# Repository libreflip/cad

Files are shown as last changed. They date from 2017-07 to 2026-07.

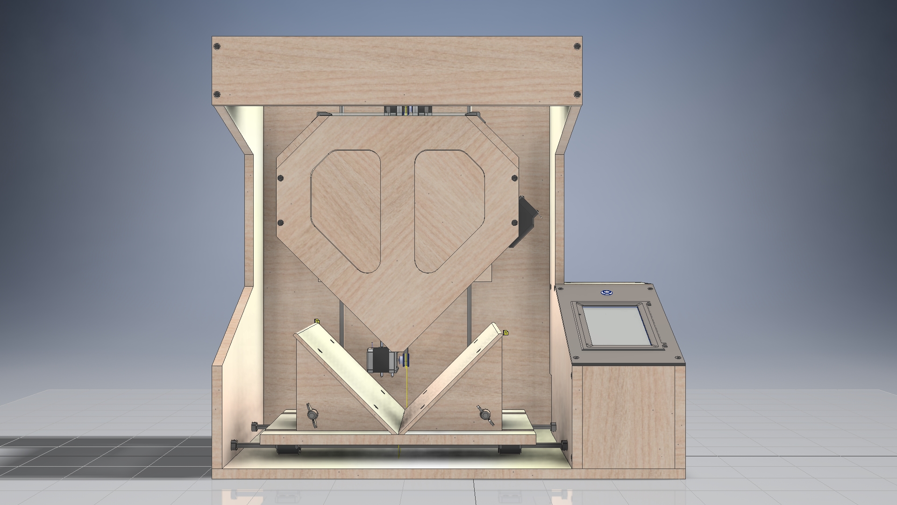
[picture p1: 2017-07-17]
img/complete5.jpg

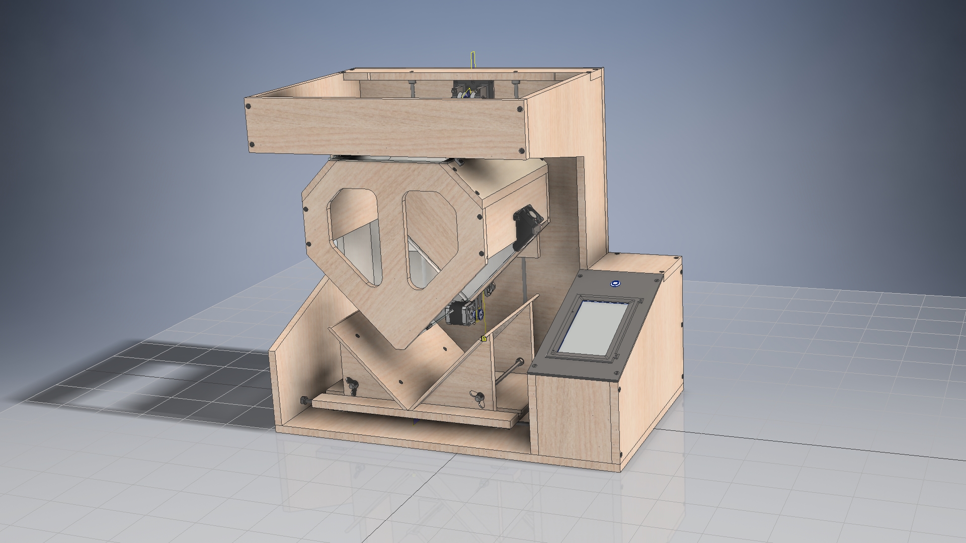
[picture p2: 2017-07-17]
img/complete1.jpg

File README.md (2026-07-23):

# Libreflip — CAD

CAD and mechanical design data for Libreflip, an open-source, automated
book scanner built at c-base Berlin.

## Contents

| Directory/File | Contents |
|---|---|
| `3d-printed/FDM/` | 3D-printable parts for standard FDM printers |
| `3d-printed/SLA/` | 3D-printable parts for resin/SLA printers |
| `drawings/` | Technical drawings (PDF) of major assemblies (backplate, suction box, fan shroud, electronics housing, bookholder, connector plate, light assembly, overview) |
| `img/` | Photos of the assembled machine |
| `plot/` | Parts list plots/exports |
| `bom_neu.ods` | Bill of materials |

## File naming

Printable parts are prefixed with the quantity needed, e.g.
`2pcs-camera-holder-movable.stl` means two of that part are required.

## ⚠️ Outdated files

`drawings/` (last updated 2018-12-31) and `plot/` (last updated 2017-07-17)
have not been updated since. Current changes and ongoing development are
**not** reflected in these files — check the individual 3D-printed part
files and their commit history for the current state instead.

## Related repositories

- [`sans`](https://github.com/libreflip/sans) — command & control software
- [`serif`](https://github.com/libreflip/serif) — web frontend
- [`monospace`](https://github.com/libreflip/monospace) — bookscanner controller firmware
- [`kerning`](https://github.com/libreflip/kerning) — deployment utilities

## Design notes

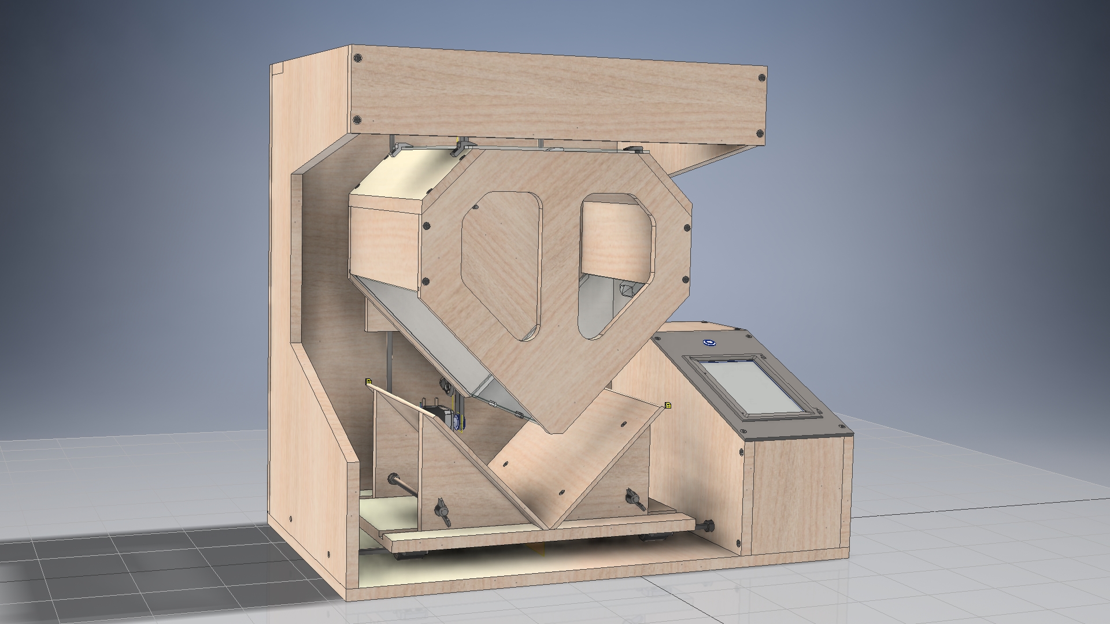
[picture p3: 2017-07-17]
img/complete2.jpg

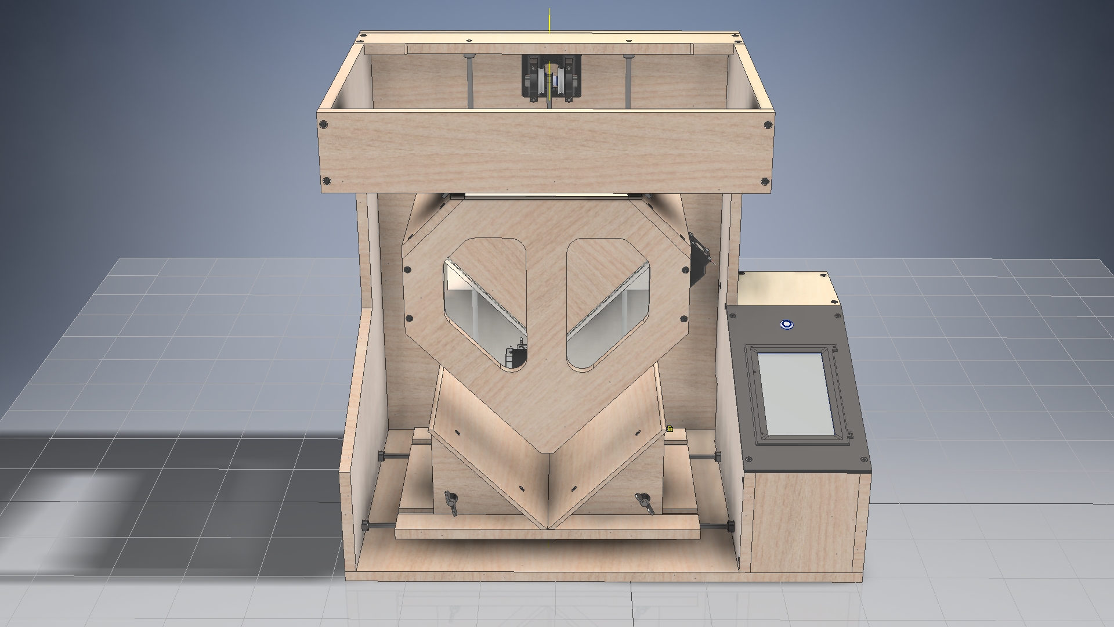
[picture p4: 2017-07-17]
img/complete6.jpg

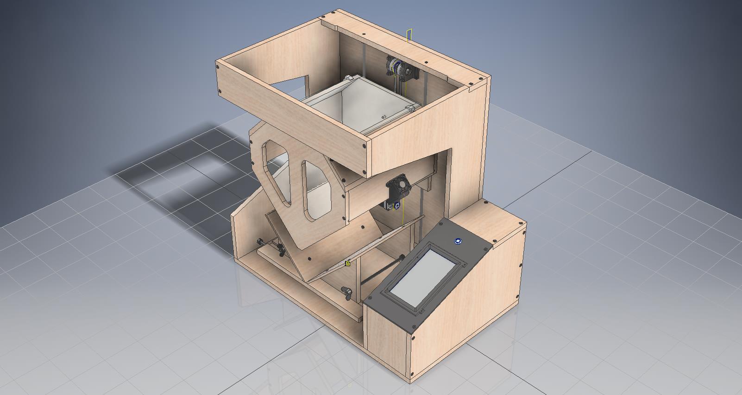
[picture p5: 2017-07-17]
img/complete3.jpg

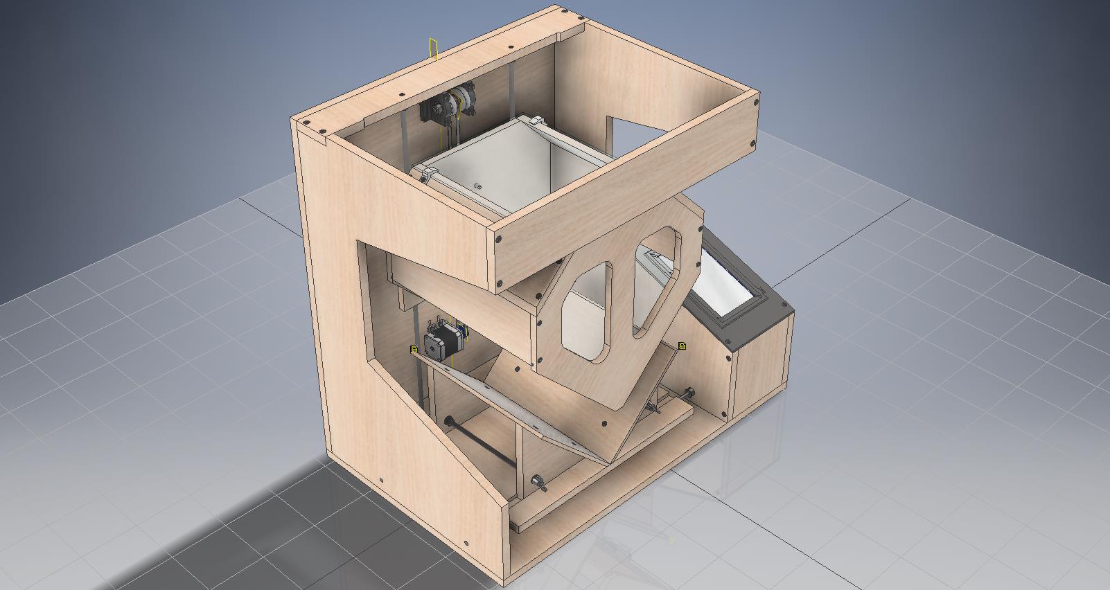
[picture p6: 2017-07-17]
img/complete4.jpg

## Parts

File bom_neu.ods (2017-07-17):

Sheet: complete-BOM
Part Number | BOM Structure | Unit QTY | QTY | Stock Number | Description | mm² | Artikel-Nr | Shop | Shoplink | Gebindegröße | Gebindepreis | Einzelpreis | Gebindemenge | Gesamtpreis | Überschuss | Preis Überschuss
5pol Kabel | Purchased |  | 1 |  | Drucksensorkabel |  |  | 0 | 0 |  | 0 | #DIV/0! | #DIV/0!
same as drucksensor kabel | Purchased |  | 1 |  | Endschalterkabel |  |  | 0 | 0 | 0 | 0 | #DIV/0! | #DIV/0!
0 | Purchased |  | 1 |  | Beleuchtungskabel |  |  | 0 | 0 | 1 | 0 | 0,0000 € | 1 | 0,00 €
0 | Purchased |  | 1 |  | Gummifedern |  |  | 0 | 0 | 1 | 0 | 0,0000 € | 1 | 0,00 €
0 | Purchased |  | 1 |  | Saugschlauch |  |  | 0 | 0 | 1 | 0 | 0,0000 € | 1 | 0,00 €
0 | Purchased |  | 1 |  | Blasschlauch |  |  | 0 | 0 | 1 | 0 | 0,0000 € | 1 | 0,00 €
0 | Purchased |  | 1 |  | Blasdüse |  |  | 0 | 0 | 1 | 0 | 0,0000 € | 1 | 0,00 €
idlershaft-mount-3dp | Normal | 1 | 1 | 0 | LQ-3DP, FDM, 0,3mm Layerheight |  |  | 3DP
pulley | Normal | 1 | 2 | 0 | LQ-3DP, FDM, 0,2mm Layerheight |  |  | 3DP
LINEAR-BEARING-HOLDER-3DP | Normal | 1 | 8 | 0 | LQ-3DP, FDM, 0,3mm Layerheight |  |  | 3DP
BELT-LOCK-3DP | Normal | 1 | 1 | 0 | LQ-3DP, FDM, 0,2mm Layerheight |  |  | 3DP
glas-separator | Normal | 1 | 2 | 0 | HQ-3DP with SLA |  |  | 3DP
TOP-GLAS-HOLDDOWN-3DP | Normal | 1 | 4 | 0 | LQ-3DP, FDM, 0,3mm Layerheight |  |  | 3DP
SHROUD-3DP | Normal | 1 | 1 | 0 | LQ-3DP, FDM, 0,2mm Layerheight |  |  | 3DP
DIN 625 T1 - 608 - 8 x 22 x 7 | Purchased | 1 | 4 | 0 | Deep Groove Ball Bearing |  | B00EPNN62M | Amazon | https://www.amazon.de/TRIXES-reibungsfreie-Kugellager-Skateboard-Roller/dp/B00WXDAUQG | 8 | 7,99 € | 0,9988 € | 1 | 7,99 € | 4 | 4,00 €
LM8UU 8mm Linear Bearing | Normal | 1 | 8 | 0 | 0 |  |  | Amazon | https://www.amazon.de/Tenflyer-Packung-Linear-Motion-Buchse/dp/B00SAHCVNE | 10 | 5,89 € | 0,5890 € | 1 | 5,89 € | 2 | 1,18 €
0 | Purchased |  | 1 |  | Lampe |  |  | Amazon | https://www.amazon.de/Superhell-Scheinwerfer-Wasserdicht-Baustrahler-6000-6500K/dp/B01MEHFIYQ/ | 1 | 28,99 | 28,9900 € | 1 | 28,99 €
Intex Luftpumpe Quick Fill | Purchased |  | 2 |  | Luftpumpe/Sauger |  |  | Amazon | https://www.amazon.de/Intex-Luftpumpe-Quick-Fill-schwarz/dp/B000QEIZJ8 | 1 | 14,7 | 14,7000 € | 2 | 29,40 €
3DP-Filament |  |  | 2 |  | Filament für 3DP |  |  | Amazon | https://www.amazon.de/05bqfil026-PLA-Spule-Drucker-Kohlschwarz/dp/B00NG69PKG/ | 1 | 23,06 | 23,0600 € | 2 | 46,12 €
antiglare-glas | Normal | 1 | 2 | 0 | 3mm AntiglareGlas 314x243mm | 76302 |  | berlinerbildergalerie.de |  | 1 | 37,32 € | 37,3200 € | 2 | 74,64 €
SUCTIONBOX-TOP-GLAS | Normal | 1 | 1 | 0 | 4mm AntiglareGlas 234x330mm |  |  | berlinerbildergalerie.de |  | 1 | 37,7700 € | 37,7700 € | 1 | 37,77 €
ISO 1035/1 - 8 - 78 | Purchased | 78,000 mm | 78,000 mm | 8 | Hot-rolled steel bars - Part 1: round bars |  | LIN08 | cncshop.at | http://www.cncshop.at/index.php?a=13360 | 1 | 2,79 € | 2,7900 € | 1 | 2,79 € | 0
ISO 1035/1 - 8 - 645 | Normal | 645,000 mm | 1290,000 mm | 8 | Hot-rolled steel bars - Part 1: round bars |  | LIN08 | cncshop.at | http://www.cncshop.at/index.php?a=13360 | 1 | 10,07 € | 10,0700 € | 2 | 20,14 € | 0
ISO 1035/1 - 8 - 540 | Normal | 540,000 mm | 1080,000 mm | 8 | Hot-rolled steel bars - Part 1: round bars |  | LIN08 | cncshop.at | http://www.cncshop.at/index.php?a=13360 | 1 | 8,37 | 8,3700 € | 2 | 16,74 € | #VALUE! | #VALUE!
See3CAM_CU130_CHL_TC | Purchased |  | 2 |  | Kamera |  |  | eCon | https://www.e-consystems.com/UltraHD-USB-Kamera-de.asp | 1 | 349 | 349,0000 € | 2 | 698,00 €
M1173041- NEMA 17 | Normal | 1 | 1 | 0 | 0 |  | EXP-R15-245 | EXP-Tech | http://www.exp-tech.de/stepper-motor-nema-17-200-steps-rev-12v-350ma | 1 | 14,5 | 14,5000 € | 1 | 14,50 €
stepper_bracket | Normal | 1 | 1 | 0 | 0 |  | EXP-R25-385 | EXP-Tech | http://www.exp-tech.de/pololu-stamped-aluminum-l-bracket-for-nema-17-stepper-motors | 1 | 3,76 | 3,7600 € | 1 | 3,76 €
Arduino Uno Rev3 | Purchased |  | 1 |  | Arduino |  | EXP-R08-002 | EXP-Tech | http://www.exp-tech.de/arduino-uno-r3 | 1 | 20,8 | 20,8000 € | 1 | 20,80 €
Rugged Metal On/Off Switch with Green LED Ring | Purchased |  | 1 |  | Powerbutton |  | EXP-R15-100 | EXP-Tech | http://www.exp-tech.de/waterproof-metal-on-off-switch-with-green-led-ring-16mm-green-on-off | 1 | 5,55 | 5,5500 € | 1 | 5,55 €
Arduino Motor Shield Rev3 | Purchased |  | 1 |  | Schrittmotortreiber |  | EXP-R08-019 | EXP-Tech | http://www.exp-tech.de/en/arduino-motor-shield-rev3?___from_store=de | 1 | 23,8 | 23,8000 € | 1 | 23,80 €
BMP183 SPI | Purchased |  | 1 |  | Drucksensor |  | EXP-R05-630 | EXP-Tech | http://www.exp-tech.de/sparkfun-barometric-pressure-sensor-bmp180-breakout-barometer-drucksensor | 1 | 11,25 | 11,2500 € | 1 | 11,25 €
Yizhet 4 Kanal Relais Modul 5V DC 230V Optokoppler 4-Channel Relay | Purchased |  | 1 |  | Relaisboard |  |  | Amazon | https://www.amazon.de/Yizhet-Optokoppler-4-Channel-Modul-Brett-Raspberry/dp/B06XJH61PD | 1 | 6,99 | 6,9900 € | 1 | 6,99 €
Odroid XU4 | Purchased |  | 1 |  | Computer |  |  | Hardkernel | http://www.hardkernel.com/main/products/prdt_info.php?g_code=G143452239825 | 1 | 59 | 59,0000 € | 1 | 59,00 €
0 | Purchased |  | 1 |  | SD-Karte 8GB |  |  | Hardkernel | http://www.hardkernel.com/main/products/prdt_info.php?g_code=G145629644581 | 1 | 8 | 8,0000 € | 1 | 8,00 €
eMMC | Purchased |  | 1 |  | Flash-Speicher 32GB |  |  | Hardkernel | http://www.hardkernel.com/main/products/prdt_info.php?g_code=G145628174287 | 1 | 41,5 | 41,5000 € | 1 | 41,50 €
Odroid VU7+ | Purchased |  | 1 |  | Touchscreen |  |  | Hardkernel | http://www.hardkernel.com/main/products/prdt_info.php?g_code=G145981837236 | 1 | 69 | 69,0000 € | 1 | 69,00 €
STRUCTURE-BACKPLATE | Normal | 1 | 1 | 0 | 15mm Plywood 675x630mm | 425250 | 400340 | Possling |  | 1000000 |  | 31,5 |  | 13,40 €
STRUCTURE-BASEPLATE | Normal | 1 | 1 | 0 | 15mm Plywood 690x430mm | 296700 | 400340 | Possling |  | 1000000 |  | 31,5000 € | Zuschnitt | 9,35 €
MOVING-BACKPLATE | Normal | 1 | 1 | 0 | 15mm Plywood 300x200mm | 60000 | 400340 | Possling |  | 1000000 |  | 31,5000 € | Zuschnitt | 1,89 €
BELT-DISTANCE-PIECE | Normal | 1 | 1 | 0 | 12mm Plywood 100x50mm | 5000 | 400545 | Possling |  | 1000000 |  | 19,4000 € | Zuschnitt | 0,10 €
LEFT-SIDEWALL | Normal | 1 | 2 | 0 | 15mm Plywood 415x630mm | 261450 | 400340 | Possling |  | 1000000 |  | 31,5000 € | Zuschnitt | 16,47 €
TOP-PLATE | Normal | 1 | 1 | 0 | 15mm Plywood 540x67mm | 36180 | 400340 | Possling |  | 1000000 |  | 31,5000 € | Zuschnitt | 1,14 €
FRONTPLATE | Normal | 1 | 1 | 0 | 15mm Plywood 540x100mm | 54000 | 400340 | Possling |  | 1000000 |  | 31,5000 € | Zuschnitt | 1,70 €
RIGHT-OUTER-SIDE | Normal | 1 | 1 | 0 | 15mm Plywood, 430x258mm | 110940 | 400340 | Possling |  | 1000000 |  | 31,5000 € | Zuschnitt | 3,49 €
FRONT-LOWER-PLATE | Normal | 1 | 1 | 0 | 15mm Plywood 150x135mm | 20250 | 400340 | Possling |  | 1000000 |  | 31,5000 € | Zuschnitt | 0,64 €
UI-PLATE | Normal | 1 | 1 | 0 | 4mm Acryl 165x316mm | 52140 | 831524 | Possling |  | 1000000 | 15,30 € | 0,0000 € | Zuschnitt | 15,30 €
HORIZONTAL-TOP-PLATE | Normal | 1 | 1 | 0 | 15mm Plywood 150x135mm | 20250 | 400340 | Possling |  | 1000000 |  | 31,5000 € | Zuschnitt | 0,64 €
BOOKHOLDER-BASE | Normal | 1 | 1 | 0 | 15mm Plywood 410x300mm | 123000 | 400340 | Possling |  | 1000000 |  | 31,5000 € | Zuschnitt | 3,87 €
VERTICAL-PART-BOOKHOLDER | Normal | 1 | 4 | 0 | 15mm Plywood 155x148mm | 22940 | 400340 | Possling |  | 1000000 |  | 31,5000 € | Zuschnitt | 2,89 €
BOOKHOLDER-PLATE | Normal | 1 | 2 | 0 | 6mm Plywood 215x300mm | 64500 | 401256 | Possling |  | 1000000 |  | 7,2000 € | Zuschnitt | 0,93 €
SUCTIONBOX-FRONT | Normal | 1 | 2 | 0 | 12mm Plywood 357x348mm | 124236 | 400545 | Possling |  | 1000000 |  | 19,4000 € | Zuschnitt | 4,82 €
SIDE-SUCTIONBOX | Normal | 1 | 2 | 0 | 12mm Plywood 104x306mm | 31824 | 400545 | Possling |  | 1000000 |  | 19,4000 € | Zuschnitt | 1,23 €
SUCTIONBOX-CAMERABOARD | Normal | 1 | 2 | 0 | 12mm Plywood 111x330mm | 36630 | 400545 | Possling |  | 1000000 |  | 19,4000 € | Zuschnitt | 1,42 €
40X40X10 DC FAN | Normal | 1 | 1 | 0 | Noiseblocker BlackSilent Fan XM2 - 40mm |  | NOISEBLOCK XM2 | Reichelt | https://www.reichelt.de/Gehaeuseluefter-40-70-mm/NOISEBLOCK-XM2/3/index.html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 | 1 | 4,7 | 4,7000 € | 1 | 4,70 € | 0
USB 3.0 4-Port Hub | Purchased |  | 1 |  | USB-Hub |  | USB3 4HUB-SW | Reichelt | https://www.reichelt.de/USB-Hubs/USB3-4HUB-SW/3/index.html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 | 1 | 19,95 | 19,9500 € | 1 | 19,95 €
0 | Purchased |  | 1 |  | USB-Kabel Arduino |  | DELOCK 83897 | Reichelt | https://www.reichelt.de/USB-Kabel/DELOCK-83897/3/index.html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 | 1 | 1,25 | 1,2500 € | 1 | 1,25 €
Neutrik | Purchased |  | 1 |  | Netzwerkbuchse |  | NEUTRIK NE-8FDP | Reichelt | https://www.reichelt.de/NEUTRIK-etherCON/NEUTRIK-NE-8FDP/3/index.html?ACTION=3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 | 1 | 9,99 | 9,9900 € | 1 | 9,99 €
Schlauchleitung H07RN - 5 x 1,5 mm², 10 m | Purchased |  | 0,7 |  | Schrittmotorkabel |  | H07RN F515 10M | Reichelt | https://www.reichelt.de/Gummi-Schlauchleitung/H07RN-F515-10M/3/index.html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 | 10 | 17,7 | 1,7700 € | 1 | 17,70 € | 9,3
0 | Purchased |  | 1 |  | Endschalter |  | AV 444461 J | Reichelt | https://www.reichelt.de/Schnappschalter-Endschalter/AV-444461-J/3/index.html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 | 1 | 1,6 | 1,6000 € | 1 | 1,60 €
 |  |  |  |  | Kaltgerätebuchse für Stromversorgung |  | KES 1SI | Reichelt
DIN 7985 (Z) - M3x10-Z | Purchased | 1 | 4 | 0 | Cross recessed raised cheese head screws - Type Z |  | 4460-100 | Wegertseder | https://www.wegertseder.com/ArticleDetails.aspx?AKNUM=4460 | 2000 | 21,66 € | 0,0108 € | 1 | 21,66 € | 1996 | 21,62 €
DIN 705 - B8 | Purchased | 1 | 12 | 0 | Adjusting Ring |  | 1860-370 | Wegertseder | https://www.wegertseder.com/ArticleDetails.aspx?AKNUM=1860 | 5 | 5,53 € | 1,1060 € | 3 | 16,59 € | 3 | 3,32 €
DIN 7991 - M5x50 | Purchased | 1 | 4 | 0 | Hexagon socket countersunk head cap screws |  | 2600-866 | Wegertseder | https://www.wegertseder.com/ArticleDetails.aspx?AKNUM=2600 | 25 | 4,00 € | 0,1600 € | 1 | 4,00 € | 21 | 3,36 €
DIN 125-1 - B 5,3 | Purchased | 1 | 4 | 0 | Washer |  | 1490-210 | Wegertseder | https://www.wegertseder.com/ArticleDetails.aspx?AKNUM=1490 | 200 | 1,38 € | 0,0069 € | 1 | 1,38 € | 196 | 1,35 €
ISO 4032 - M5 | Purchased | 1 | 4 | 0 | Hex Nut |  | 2888-012 | Wegertseder | https://www.wegertseder.com/ArticleDetails.aspx?AKNUM=2888 | 100 | 1,68 € | 0,0168 € | 1 | 1,68 € | 96 | 1,61 €
Screws for wood 4x16 | Normal | 1 | 13 | 0 | 0 |  | 1402-854 | Wegertseder | https://www.wegertseder.com/ArticleDetails.aspx?AKNUM=1402&Diameter=4 | 100 | 2,31 € | 0,0231 € | 1 | 2,31 € | 87 | 2,01 €
DIN 580 - M8 | Purchased | 1 | 2 | 0 | Lifting Eyebolt |  | 3680-366 | Wegertseder | https://www.wegertseder.com/ArticleDetails.aspx?AKNUM=3680&Diameter=25 | 25 | 4,97 € | 0,1988 € | 1 | 4,97 € | 23 | 4,57 €
Screws for wood 4x40 | Normal | 1 | 69 | 0 | 0 |  | 1402-864 | Wegertseder | https://www.wegertseder.com/ArticleDetails.aspx?AKNUM=1402&Diameter=4 | 100 | 2,45 € | 0,0245 € | 1 | 2,45 € | 31 | 0,76 €
ISO 4017 - M4 x 25 | Purchased | 1 | 4 | 0 | Hexagon head screws |  | 2748-021 | Wegertseder | https://www.wegertseder.com/ArticleDetails.aspx?AKNUM=2748&Diameter=4 | 50 | 3,49 € | 0,0698 € | 1 | 3,49 € | 46 | 3,21 €
DIN 125-1 - B 4,3 | Purchased | 1 | 4 | 0 | Washer |  | 1490-208 | Wegertseder | https://www.wegertseder.com/ArticleDetails.aspx?AKNUM=1490 | 200 | 1,19 € | 0,0060 € | 1 | 1,19 € | 196 | 1,17 €
ISO 4032 - M4 | Purchased | 1 | 4 | 0 | Hex Nut |  | 2888-010 | Wegertseder | https://www.wegertseder.com/ArticleDetails.aspx?AKNUM=2888 | 100 | 1,78 € | 0,0178 € | 1 | 1,78 € | 96 | 1,71 €
Screws for wood 4x20 | Normal | 1 | 48 | 0 | 0 |  | 1402-856 | Wegertseder | https://www.wegertseder.com/ArticleDetails.aspx?AKNUM=1402 | 100 | 2,50 € | 0,0250 € | 1 | 2,50 € | 52 | 1,30 €
DIN 603 - M6 x 25 | Purchased | 1 | 2 | 0 | Cup Head Square Neck Bolt |  | 2296-494 | Wegertseder | https://www.wegertseder.com/ArticleDetails.aspx?AKNUM=2296 | 50 | 8,72 € | 0,1744 € | 1 | 8,72 € | 48 | 8,37 €
DIN 125-1 - B 6,4 | Purchased | 1 | 2 | 0 | Washer |  | 1490-212 | Wegertseder | https://www.wegertseder.com/ArticleDetails.aspx?AKNUM=1490 | 200 | 2,19 € | 0,0110 € | 1 | 2,19 € | 198 | 2,17 €
ISO 4032 - M6 | Purchased | 1 | 2 | 0 | Hex Nut |  | 2888-014 | Wegertseder | https://www.wegertseder.com/ArticleDetails.aspx?AKNUM=2888 | 100 | 1,98 € | 0,0198 € | 1 | 1,98 € | 98 | 1,94 €
DIN 603 - M6 x 30 | Purchased | 1 | 2 | 0 | Cup Head Square Neck Bolt |  | 2296-496 | Wegertseder | https://www.wegertseder.com/ArticleDetails.aspx?AKNUM=2296 | 50 | 8,12 € | 0,1624 € | 1 | 8,12 € | 48 | 7,80 €
ISO 4032 - M8 | Purchased | 1 | 4 | 0 | Hex Nut |  | 2888-018 | Wegertseder | https://www.wegertseder.com/ArticleDetails.aspx?AKNUM=2888 | 100 | 2,56 € | 0,0256 € | 1 | 2,56 € | 96 | 2,46 €
DIN 125-1 - B 8,4 | Purchased | 1 | 6 | 0 | Washer |  | 1490-216 | Wegertseder | https://www.wegertseder.com/ArticleDetails.aspx?AKNUM=1490 | 100 | 2,74 € | 0,0274 € | 1 | 2,74 € | 94 | 2,58 €
DIN 315 - M8 | Purchased | 1 | 2 | 0 | Wing Nut |  | 2018-172 | Wegertseder | https://www.wegertseder.com/ArticleDetails.aspx?AKNUM=2018 | 10 | 5,80 € | 0,5800 € | 1 | 5,80 € | 8 | 4,64 €
DIN 976-1 - M8 x 1000 - A | Purchased | 1 | 2 | 0 | Stud bolts - Part 1: Metric thread |  | 2190-630 | Wegertseder | https://www.wegertseder.com/ArticleDetails.aspx?AKNUM=2190&Diameter=8 | 1 | 1,80 € | 1,8000 € | 2 | 3,60 € | 0
DIN 7985 (Z) - M3x16-Z | Purchased | 1 | 4 | 0 | Cross recessed raised cheese head screws - Type Z |  | 4460-104 | Wegertseder | https://www.wegertseder.com/ArticleDetails.aspx?AKNUM=4460 | 2000 | 15,47 € | 0,0077 € | 1 | 15,47 € | 1996 | 15,44 €
Screws for wood 4x12 | Normal | 1 | 2 | 0 | 0 |  | 1390-198 | Wegertseder | https://www.wegertseder.com/ArticleDetails.aspx?AKNUM=1390&Diameter=4 | 200 | 2,95 | 0,0148 € | 1 | 2,95 € | 198 | 2,92 €
16T2.5-24-2 | Normal | 1 | 2 | 0 | 0 |  | 410900 | Zahnriemen24 | https://www.zahnriemen24.de/raeder-und-scheiben/zahnscheiben-t-und-at-profil/t2-5-zahnriemenscheibe/ | 1 | 7,59 € | 7,5900 € | 2 | 15,18 € | 0
Synchronous Belt | Normal | 1 | 1 | 0 | Zahnriemen 6-T2,5-950 |  | 320728 | Zahnriemen24 | https://www.zahnriemen24.de/zahnriemen/pu-t-profil/t25/#/zahnriemen-6-t2,5-950/ | 1 | 15,65 € | 15,6500 € | 1 | 15,65 € | 0

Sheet: Inventor-export
Item | Part Number | Thumbnail | BOM Structure | Unit QTY | QTY | Stock Number | Description
01 | STRUCTURE-BACKPLATE | (NonDisplayable) | Normal | 1 | 1 |  | 15mm Plywood 675x630mm
02 | M1173041- NEMA 17 | (NonDisplayable) | Normal | 1 | 1
03 | stepper_bracket | (NonDisplayable) | Normal | 1 | 1
04 | DIN 7985 (Z) - M3x10-Z | (NonDisplayable) | Purchased | 1 | 4 |  | Cross recessed raised cheese head screws - Type Z
05 | 16T2.5-24-2 | (NonDisplayable) | Normal | 1 | 2
06 | idlershaft-mount-3dp | (NonDisplayable) | Normal | 1 | 1 |  | LQ-3DP, FDM, 0,3mm Layerheight
07 | DIN 625 T1 - 608 - 8 x 22 x 7 | (NonDisplayable) | Purchased | 1 | 4 |  | Deep Groove Ball Bearing
08 | DIN 705 - B8 | (NonDisplayable) | Purchased | 1 | 10 |  | Adjusting Ring
09 | ISO 1035/1 - 8 - 78 | (NonDisplayable) | Purchased | 78,000 mm | 78,000 mm | 8 | Hot-rolled steel bars - Part 1: round bars
10 | pulley | (NonDisplayable) | Normal | 1 | 2 |  | LQ-3DP, FDM, 0,2mm Layerheight
11 | DIN 7991 - M5x50 | (NonDisplayable) | Purchased | 1 | 4 |  | Hexagon socket countersunk head cap screws
12 | DIN 125-1 - B 5,3 | (NonDisplayable) | Purchased | 1 | 4 |  | Washer
13 | ISO 4032 - M5 | (NonDisplayable) | Purchased | 1 | 4 |  | Hex Nut
14 | Screws for wood 4x16 | (NonDisplayable) | Normal | 1 | 13
15 | Synchronous Belt | (NonDisplayable) | Normal | 1 | 1 |  | LQ-3DP, FDM, 0,3mm Layerheight
16 | DIN 580 - M8 | (NonDisplayable) | Purchased | 1 | 2 |  | Lifting Eyebolt
17 | Screws for wood 4x40 | (NonDisplayable) | Normal | 1 | 69
18 | ISO 4017 - M4 x 25 | (NonDisplayable) | Purchased | 1 | 4 |  | Hexagon head screws
19 | DIN 125-1 - B 4,3 | (NonDisplayable) | Purchased | 1 | 4 |  | Washer
20 | ISO 4032 - M4 | (NonDisplayable) | Purchased | 1 | 4 |  | Hex Nut
21 | STRUCTURE-BASEPLATE | (NonDisplayable) | Normal | 1 | 1 |  | 15mm Plywood 690x430mm
22 | MOVING-BACKPLATE | (NonDisplayable) | Normal | 1 | 1 |  | 15mm Plywood 300x200mm
23 | LINEAR-BEARING-HOLDER-3DP | (NonDisplayable) | Normal | 1 | 8 |  | LQ-3DP, FDM, 0,3mm Layerheight
24 | LM8UU 8mm Linear Bearing | (NonDisplayable) | Normal | 1 | 8
25 | Screws for wood 4x20 | (NonDisplayable) | Normal | 1 | 48
26 | BELT-DISTANCE-PIECE | (NonDisplayable) | Normal | 1 | 1 |  | 12mm Plywood 100x50mm
27 | DIN 603 - M6 x 25 | (NonDisplayable) | Purchased | 1 | 2 |  | Cup Head Square Neck Bolt
28 | BELT-LOCK-3DP | (NonDisplayable) | Normal | 1 | 1 |  | LQ-3DP, FDM, 0,2mm Layerheight
29 | DIN 125-1 - B 6,4 | (NonDisplayable) | Purchased | 1 | 2 |  | Washer
30 | ISO 4032 - M6 | (NonDisplayable) | Purchased | 1 | 2 |  | Hex Nut
31 | DIN 603 - M6 x 30 | (NonDisplayable) | Purchased | 1 | 2 |  | Cup Head Square Neck Bolt
32 | ISO 1035/1 - 8 - 645 | (NonDisplayable) | Normal | 645,000 mm | 1290,000 mm | 8 | Hot-rolled steel bars - Part 1: round bars
33 | LEFT-SIDEWALL | *Varies* | Normal | 1 | 2 |  | 15mm Plywood 415x630mm
34 | TOP-PLATE | (NonDisplayable) | Normal | 1 | 1 |  | 15mm Plywood 540x67mm
35 | FRONTPLATE | (NonDisplayable) | Normal | 1 | 1 |  | 15mm Plywood 540x100mm
36 | RIGHT-OUTER-SIDE | (NonDisplayable) | Normal | 1 | 1 |  | 15mm Plywood, 430x258mm
37 | FRONT-LOWER-PLATE | (NonDisplayable) | Normal | 1 | 1 |  | 15mm Plywood 150x135mm
38 | UI-PLATE | (NonDisplayable) | Normal | 1 | 1 |  | 4mm Acryl 165x316mm
39 | HORIZONTAL-TOP-PLATE | (NonDisplayable) | Normal | 1 | 1 |  | 15mm Plywood 150x135mm
40 | BOOKHOLDER-BASE | (NonDisplayable) | Normal | 1 | 1 |  | 15mm Plywood 410x300mm
41 | VERTICAL-PART-BOOKHOLDER | (NonDisplayable) | Normal | 1 | 4 |  | 15mm Plywood 155x148mm
42 | BOOKHOLDER-PLATE | (NonDisplayable) | Normal | 1 | 2 |  | 6mm Plywood 215x300mm
43 | ISO 4032 - M8 | (NonDisplayable) | Purchased | 1 | 4 |  | Hex Nut
44 | DIN 125-1 - B 8,4 | *Varies* | Purchased | 1 | 6 |  | Washer
45 | DIN 315 - M8 | (NonDisplayable) | Purchased | 1 | 2 |  | Wing Nut
46 | DIN 976-1 - M8 x 1000 - A | (NonDisplayable) | Purchased | 1 | 2 |  | Stud bolts - Part 1: Metric thread
47 | antiglare-glas | (NonDisplayable) | Normal | 1 | 2 |  | 3mm AntiglareGlas 314x243mm
48 | glas-separator | (NonDisplayable) | Normal | 1 | 2 |  | HQ-3DP with SLA
49 | SUCTIONBOX-FRONT | *Varies* | Normal | 1 | 2 |  | 12mm Plywood 357x348mm
50 | SIDE-SUCTIONBOX | (NonDisplayable) | Normal | 1 | 2 |  | 12mm Plywood 104x306mm
51 | SUCTIONBOX-CAMERABOARD | (NonDisplayable) | Normal | 1 | 2 |  | 12mm Plywood 111x330mm
52 | SUCTIONBOX-TOP-GLAS | (NonDisplayable) | Normal | 1 | 1 |  | 4mm AntiglareGlas 234x330mm
53 | TOP-GLAS-HOLDDOWN-3DP | (NonDisplayable) | Normal | 1 | 4 |  | LQ-3DP, FDM, 0,3mm Layerheight
54 | DUMMYSHAPE-FLUTTERFAN | (NonDisplayable) | Normal | 1 | 0
55 | 40X40X10 DC FAN | (NonDisplayable) | Normal | 1 | 1
56 | SHROUD-3DP | (NonDisplayable) | Normal | 1 | 1 |  | LQ-3DP, FDM, 0,2mm Layerheight
57 | DIN 7985 (Z) - M3x16-Z | (NonDisplayable) | Purchased | 1 | 4 |  | Cross recessed raised cheese head screws - Type Z
58 | Screws for wood 4x12 | (NonDisplayable) | Normal | 1 | 2
59 | ISO 1035/1 - 8 - 540 | (NonDisplayable) | Normal | 540,000 mm | 1080,000 mm | 8 | Hot-rolled steel bars - Part 1: round bars

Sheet: manual-bom
Name | Produktbezeichnung | Funktion | Quelle | Maße | notw. Menge | Einzelpreis | Preis / VE | Stck / VE | Menge VE | Preis alle VE | Währung | Shop | Shoplink | 3D-Modell | Datenblatt
 | Odroid XU4 | Computer | Kaufen |  | 1 |  |  |  | 1 | 59 | USD | Hardkernel
 |  | SD-Karte 8GB | Kaufen |  | 1 |  |  |  | 1 | 8 | USD | Hardkernel
 | eMMC | Flash-Speicher 32GB | Kaufen |  | 1 |  |  |  | 1 | 41,5 | USD | Hardkernel
 | Odroid VU7+ | Touchscreen | Kaufen |  | 1 |  |  |  | 1 | 69 | USD | Hardkernel
 | See3CAM_CU130 | Kamera | Kaufen |  | 2 |  |  |  | 1 | 349 | USD | eCon
 | Arduino Uno Rev3 | Arduino | Kaufen |  | 1 |  |  |  | 1 | 18,5 | EUR | Reichelt | https://www.reichelt.de/Einplatinen-Microcontroller/ARDUINO-MICRO/3/index.html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
USB3.0 Hub |  | USB-Hub | Kaufen |  | 1 |  |  |  | 1 | 19,95 | EUR | Reichelt | https://www.reichelt.de/USB-Hubs/USB3-4HUB-SW/3/index.html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
 |  | USB-Kabel Arduino | Kaufen |  | 1 |  |  |  | 1 | 1,25 | EUR | Reichelt | https://www.reichelt.de/USB-Kabel/DELOCK-83897/3/index.html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
 | Neutrik | Netzwerkbuchse | Kaufen |  | 1 |  |  |  | 1 | 9,99 | EUR | Reichelt | https://www.reichelt.de/NEUTRIK-etherCON/NEUTRIK-NE-8FDP/3/index.html?ACTION=3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
 |  | Powerbutton | Kaufen |  | 1 |  |  |  | 1 | 5,55 | EUR | EXP-Tech | http://www.exp-tech.de/waterproof-metal-on-off-switch-with-green-led-ring-16mm-green-on-off
 | Pololu | Schrittmotortreiber | Kaufen |  | 1 |  |  |  | 1 | 7,95 | EUR | EXP-Tech | http://www.exp-tech.de/a4988-stepper-motor-driver-carrier-black-edition
 |  | Schrittmotorkabel | Kaufen |  | 1
 | BMP183 SPI | Drucksensor | Kaufen |  | 1 |  |  |  | 1 | 10,95 | EUR | EXP-Tech | http://www.exp-tech.de/sparkfun-barometric-pressure-sensor-bmp180-breakout-barometer-drucksensor
Kabel | 5pol Kabel | Drucksensorkabel | Kaufen |  | 1
Maschinentaster |  | Endschalter | Kaufen |  | 1 |  |  |  | 1 | 1,6 | EUR | Reichelt | https://www.reichelt.de/Schnappschalter-Endschalter/AV-444461-J/3/index.html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
 |  | Endschalterkabel | Kaufen |  | 1
Sainsmart |  | Relaisboard | Kaufen |  | 1
 |  | Lampe | Kaufen |  | 2 |  |  |  | 1 | 28,99 | EUR | Amazon | https://www.amazon.de/Superhell-Scheinwerfer-Wasserdicht-Baustrahler-6000-6500K/dp/B01MEHFIYQ/
 |  | Beleuchtungskabel | Kaufen |  | 1
 |  | Gummifedern | Kaufen
 |  | Saugschlauch | Kaufen
 |  | Blasschlauch | Kaufen
 |  | Blasdüse | 3DP
 |  | Kabelführung | Kaufen

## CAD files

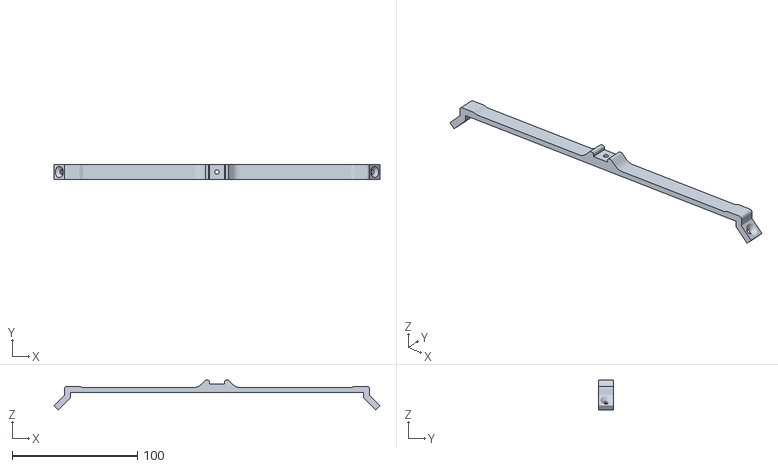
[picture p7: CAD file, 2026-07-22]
3d-printed/FDM/2pcs-lightholder-new.stl
260.3 x 12.0 x 24.0

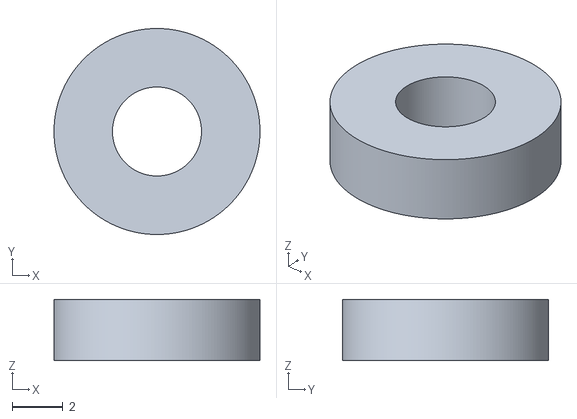
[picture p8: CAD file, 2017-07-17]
3d-printed/SLA/5pcs-distancepiece.stl
8.10 x 8.10 x 2.40

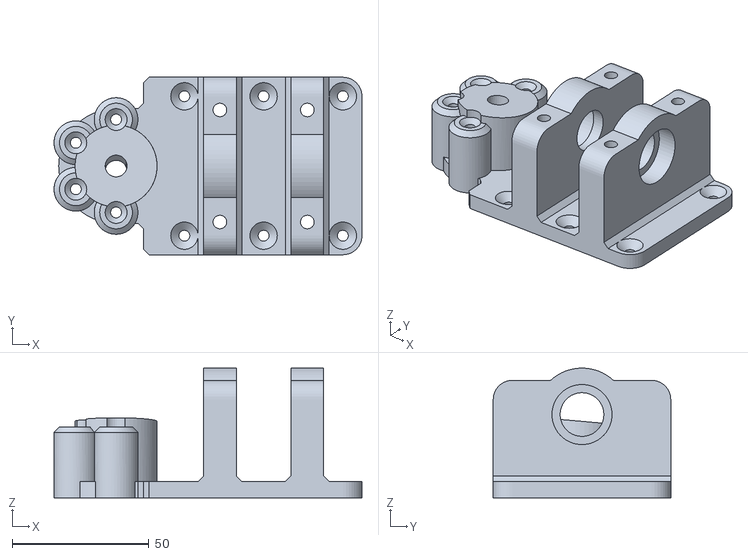
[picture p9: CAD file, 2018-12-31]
3d-printed/FDM/1pcs-idlershaft-mount-v3.stl
112.7 x 65.0 x 47.5

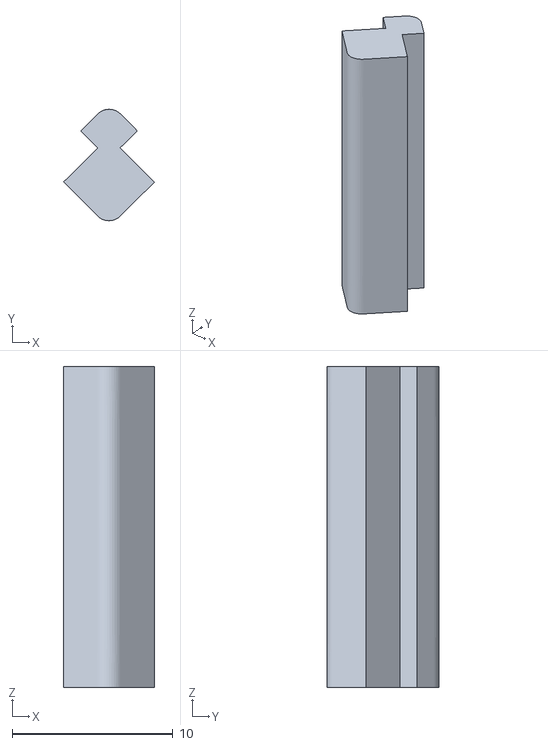
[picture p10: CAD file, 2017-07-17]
3d-printed/SLA/3pcs-glas-separator.stl
5.66 x 6.95 x 20.0

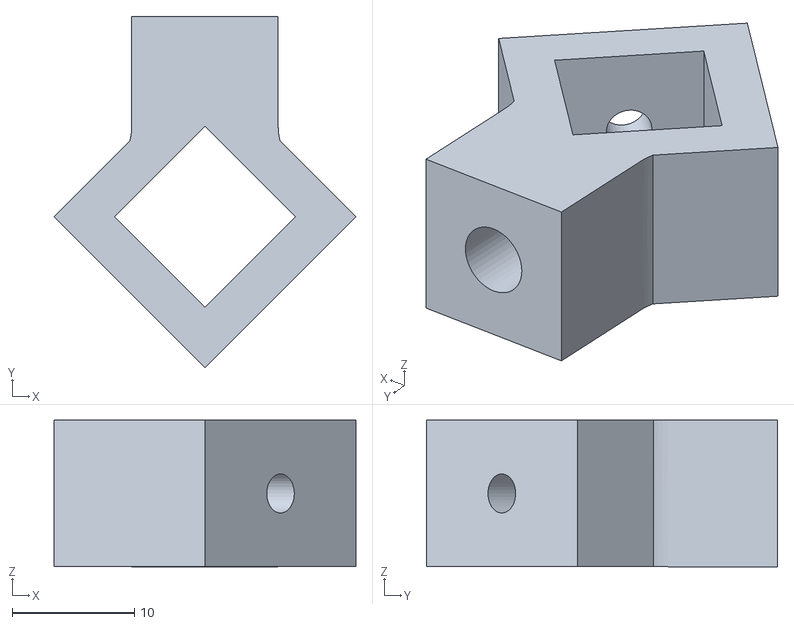
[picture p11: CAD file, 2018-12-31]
3d-printed/FDM/2pcs-light-rod-holder-upper-3dp.stl
24.7 x 28.8 x 12.0

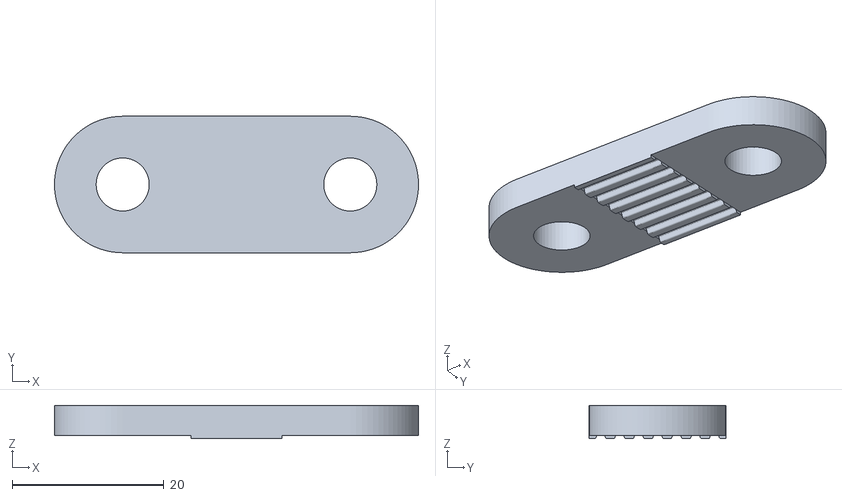
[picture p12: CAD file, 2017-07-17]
3d-printed/SLA/1pcs-belt-lock.stl
48.0 x 18.0 x 4.38

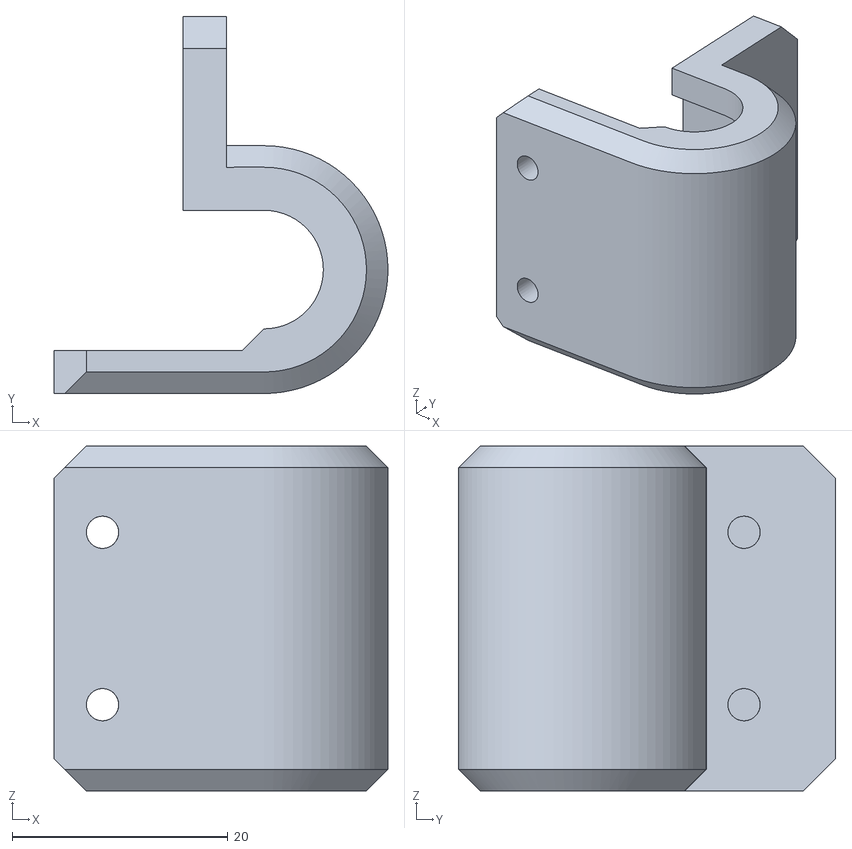
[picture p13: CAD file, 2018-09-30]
3d-printed/FDM/2pcs-CW-bearing-holder-orient1-3dp.stl
31.0 x 35.0 x 32.0

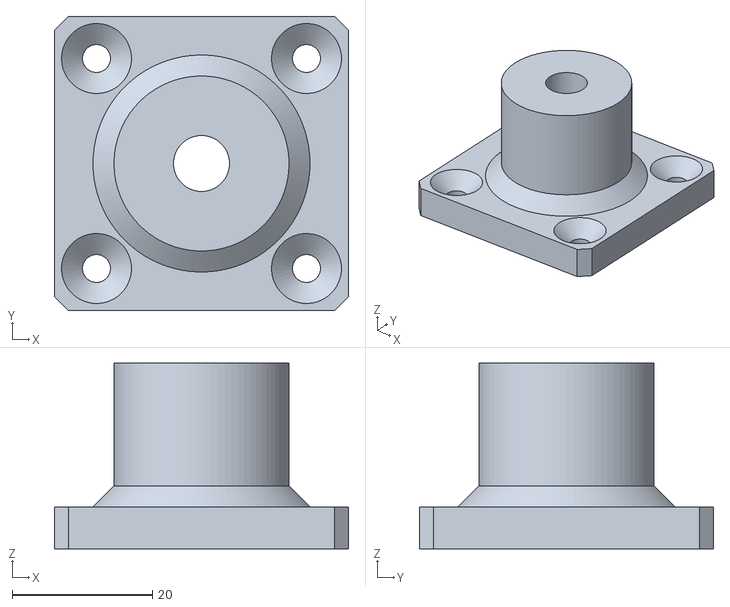
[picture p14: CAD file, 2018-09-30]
3d-printed/FDM/1pcs-counterweight-pulley-3dp.stl
42.0 x 42.0 x 26.5

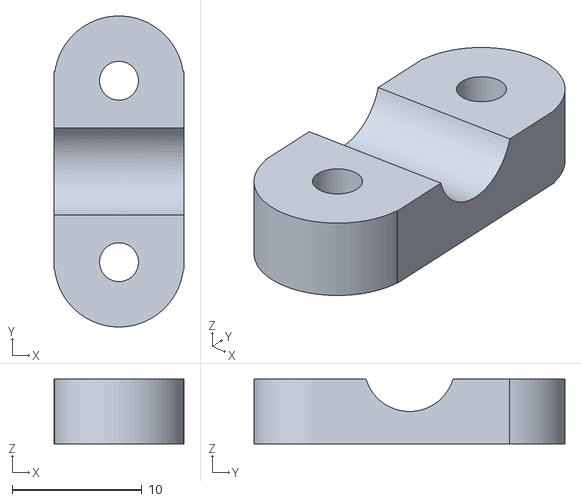
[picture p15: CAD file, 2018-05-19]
3d-printed/FDM/1pcs-baro-sens-cable-HOLDclamp-3dp.stl
10.0 x 24.0 x 5.00

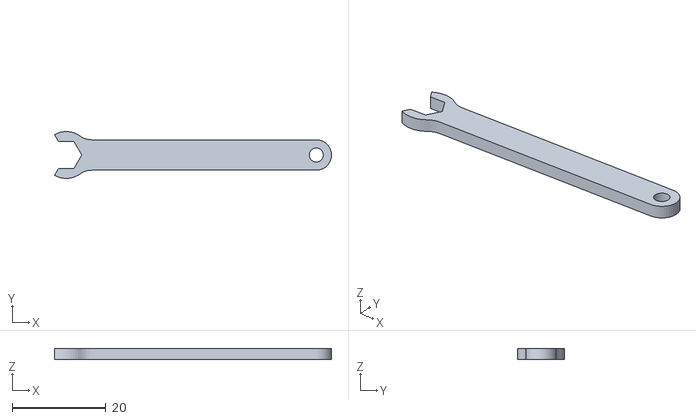
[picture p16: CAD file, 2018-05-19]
3d-printed/FDM/1pcs-m4-wrench.stl
59.0 x 9.99 x 2.40

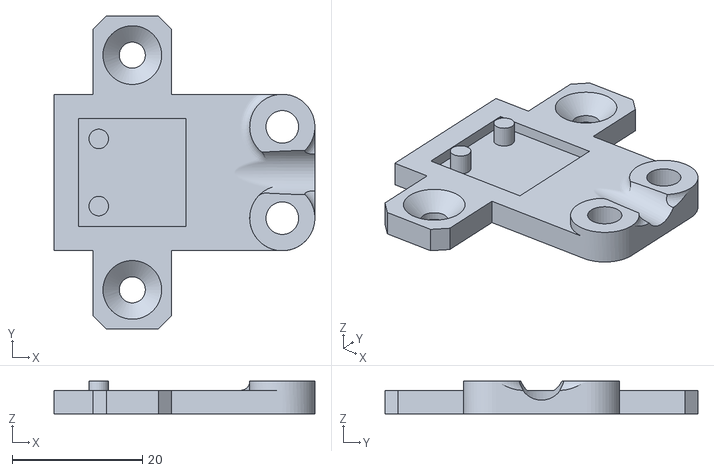
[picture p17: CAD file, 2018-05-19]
3d-printed/FDM/1pcs-baro-sensor-holder-3dp.stl
40.0 x 48.0 x 5.00

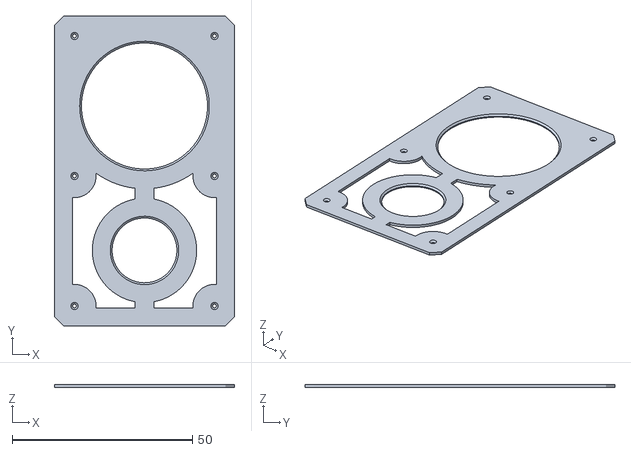
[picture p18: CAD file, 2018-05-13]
3d-printed/FDM/1pcs-hose-adapter-drilltemplate-3dp.stl
50.0 x 86.1 x 0.8

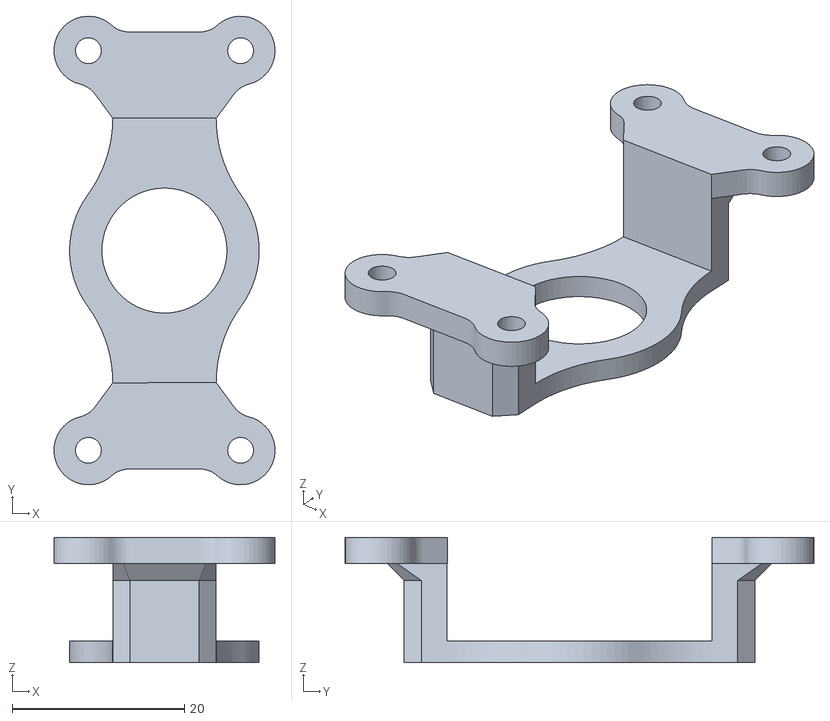
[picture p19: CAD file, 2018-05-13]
3d-printed/FDM/2pcs-camera-holddown.stl
25.6 x 54.4 x 14.5

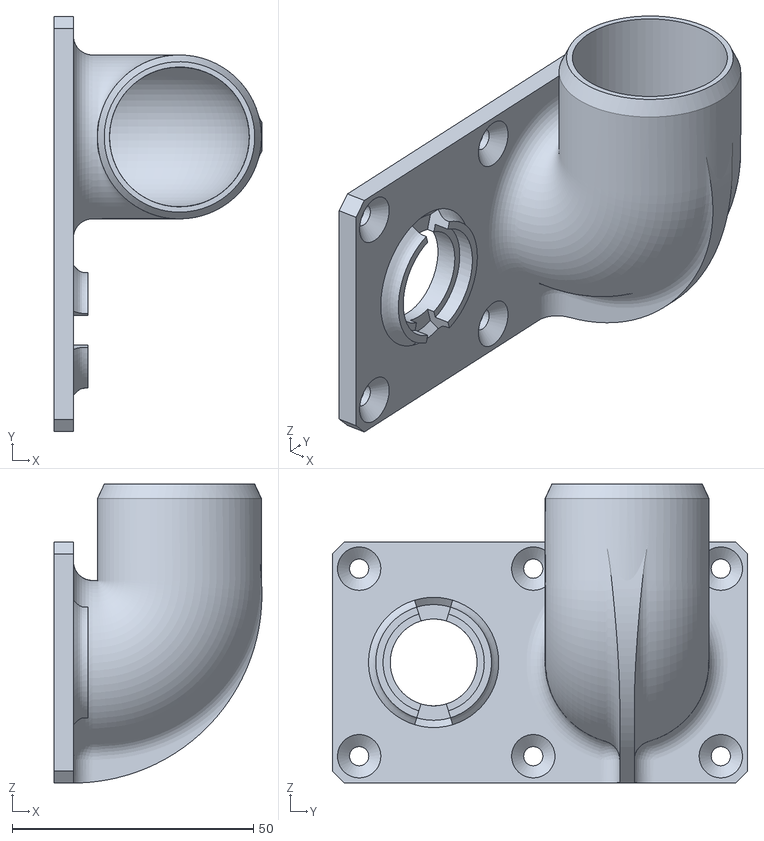
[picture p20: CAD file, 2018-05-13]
3d-printed/FDM/1pcs-hose-adapter-suctionbox-3dp.stl
43.1 x 86.1 x 62.0

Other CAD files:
plot/total-parts-plot2.dwg
plot/total-parts-plot.dwg
3d-printed/FDM/2pcs-CW-bearing-holder-orient2-3dp.stl
3d-printed/FDM/2pcs-camera-holder-movable.stl
3d-printed/FDM/1pcs-displayframe-3dp.stl
3d-printed/FDM/1pcs-double-tube-holder-3dp.stl
3d-printed/FDM/1pcs-hose-adapter-bulkhead-lower-3dp.stl
3d-printed/FDM/1pcs-hose-adapter-bulkhead-upper-3dp.stl
3d-printed/FDM/1pcs-idlershaft-mount-v2.stl
3d-printed/FDM/1pcs-idlershaft-mount.stl
3d-printed/FDM/1pcs-m4-wrench.ipt
3d-printed/FDM/1pcs-nozzle-blower-3dp.stl
3d-printed/FDM/1pcs-rubber-holder-8mm-3dp-test.stl
3d-printed/FDM/1pcs-shroud-flutterfan.stl
3d-printed/FDM/1pcs-shroud-v2-3dp.stl
3d-printed/FDM/1pcs-tube-holder--flat-3dp.stl
3d-printed/FDM/2pcs-camera-holder-fixed.stl
3d-printed/FDM/2pcs-pulley.stl
3d-printed/FDM/4pcs-glas-holddown.stl
3d-printed/FDM/4pcs-tube-holder-3dp.stl
3d-printed/FDM/8pcs-linear-bearing-holder.stl
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

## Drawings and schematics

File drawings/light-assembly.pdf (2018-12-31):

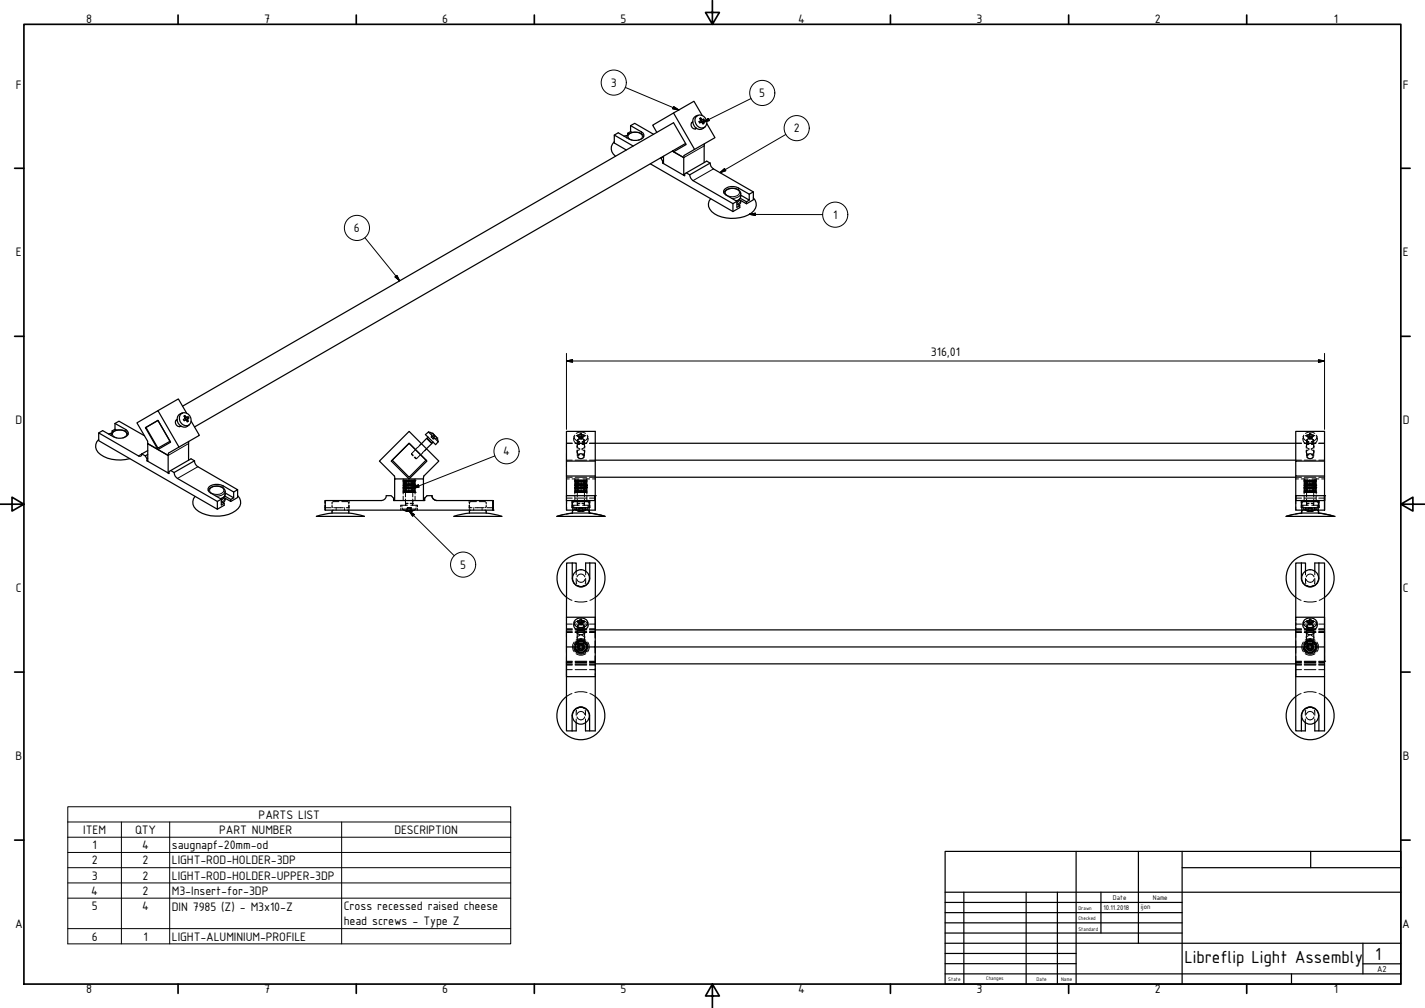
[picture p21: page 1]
PARTS LIST; ITEM; QTY; PART NUMBER; DESCRIPTION; saugnapf-20mm-od; LIGHT-ROD-HOLDER-3DP; LIGHT-ROD-HOLDER-UPPER-3DP; M3-Insert-for-3DP; DIN 7985 (Z) - M3x10-Z; LIGHT-ALUMINIUM-PROFILE; State; Changes; Date; Name; Drawn; Checked; Standard; ijon

Cross recessed raised cheese
head screws - Type Z

Libreflip Light Assembly

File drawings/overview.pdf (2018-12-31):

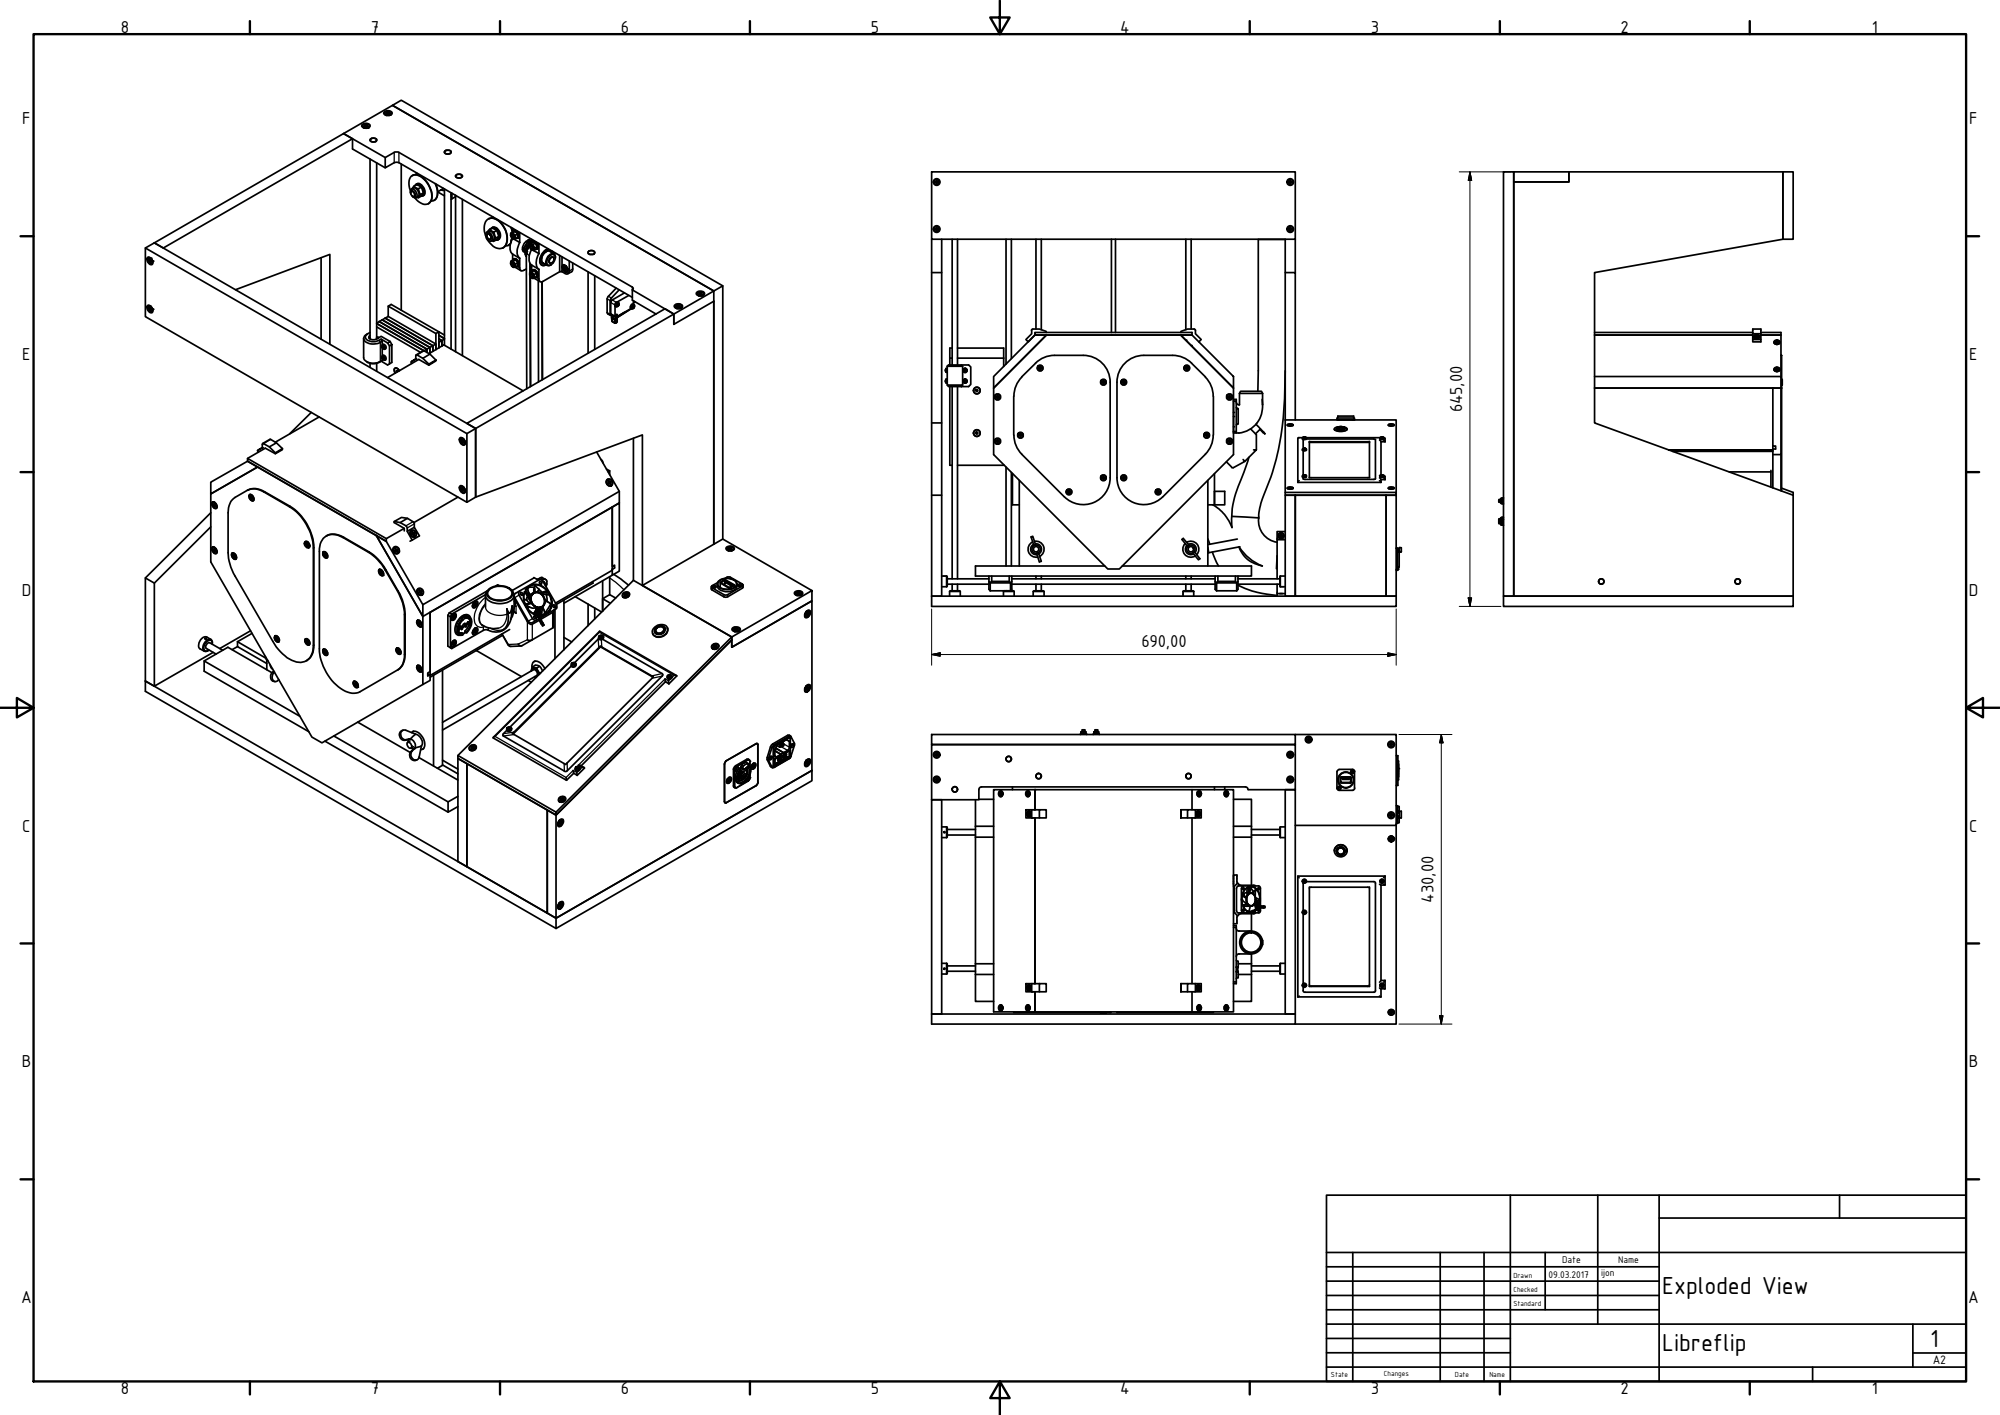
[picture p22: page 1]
Exploded View; Libreflip; State; Changes; Date; Name; Drawn; Checked; Standard; ijon

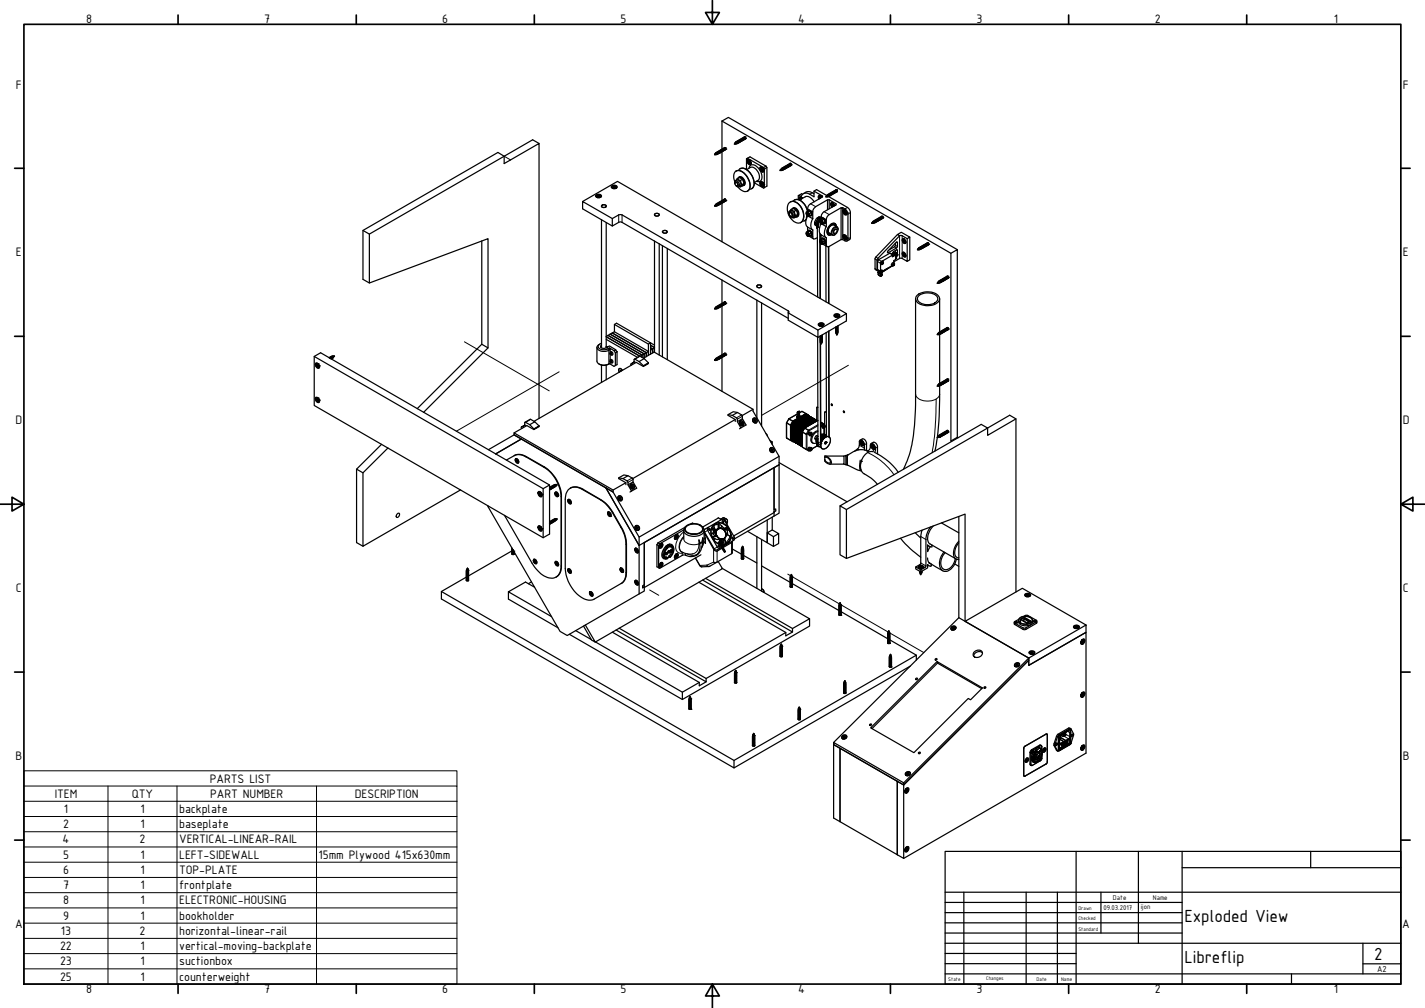
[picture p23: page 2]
PARTS LIST; ITEM; QTY; PART NUMBER; DESCRIPTION; backplate; baseplate; VERTICAL-LINEAR-RAIL; LEFT-SIDEWALL; 15mm Plywood 415x630mm; TOP-PLATE; frontplate; ELECTRONIC-HOUSING; bookholder; horizontal-linear-rail; vertical-moving-backplate; suctionbox; counterweight; Exploded View; Drawn; Checked; Date; Name; ijon

# Libreflip

# automatic

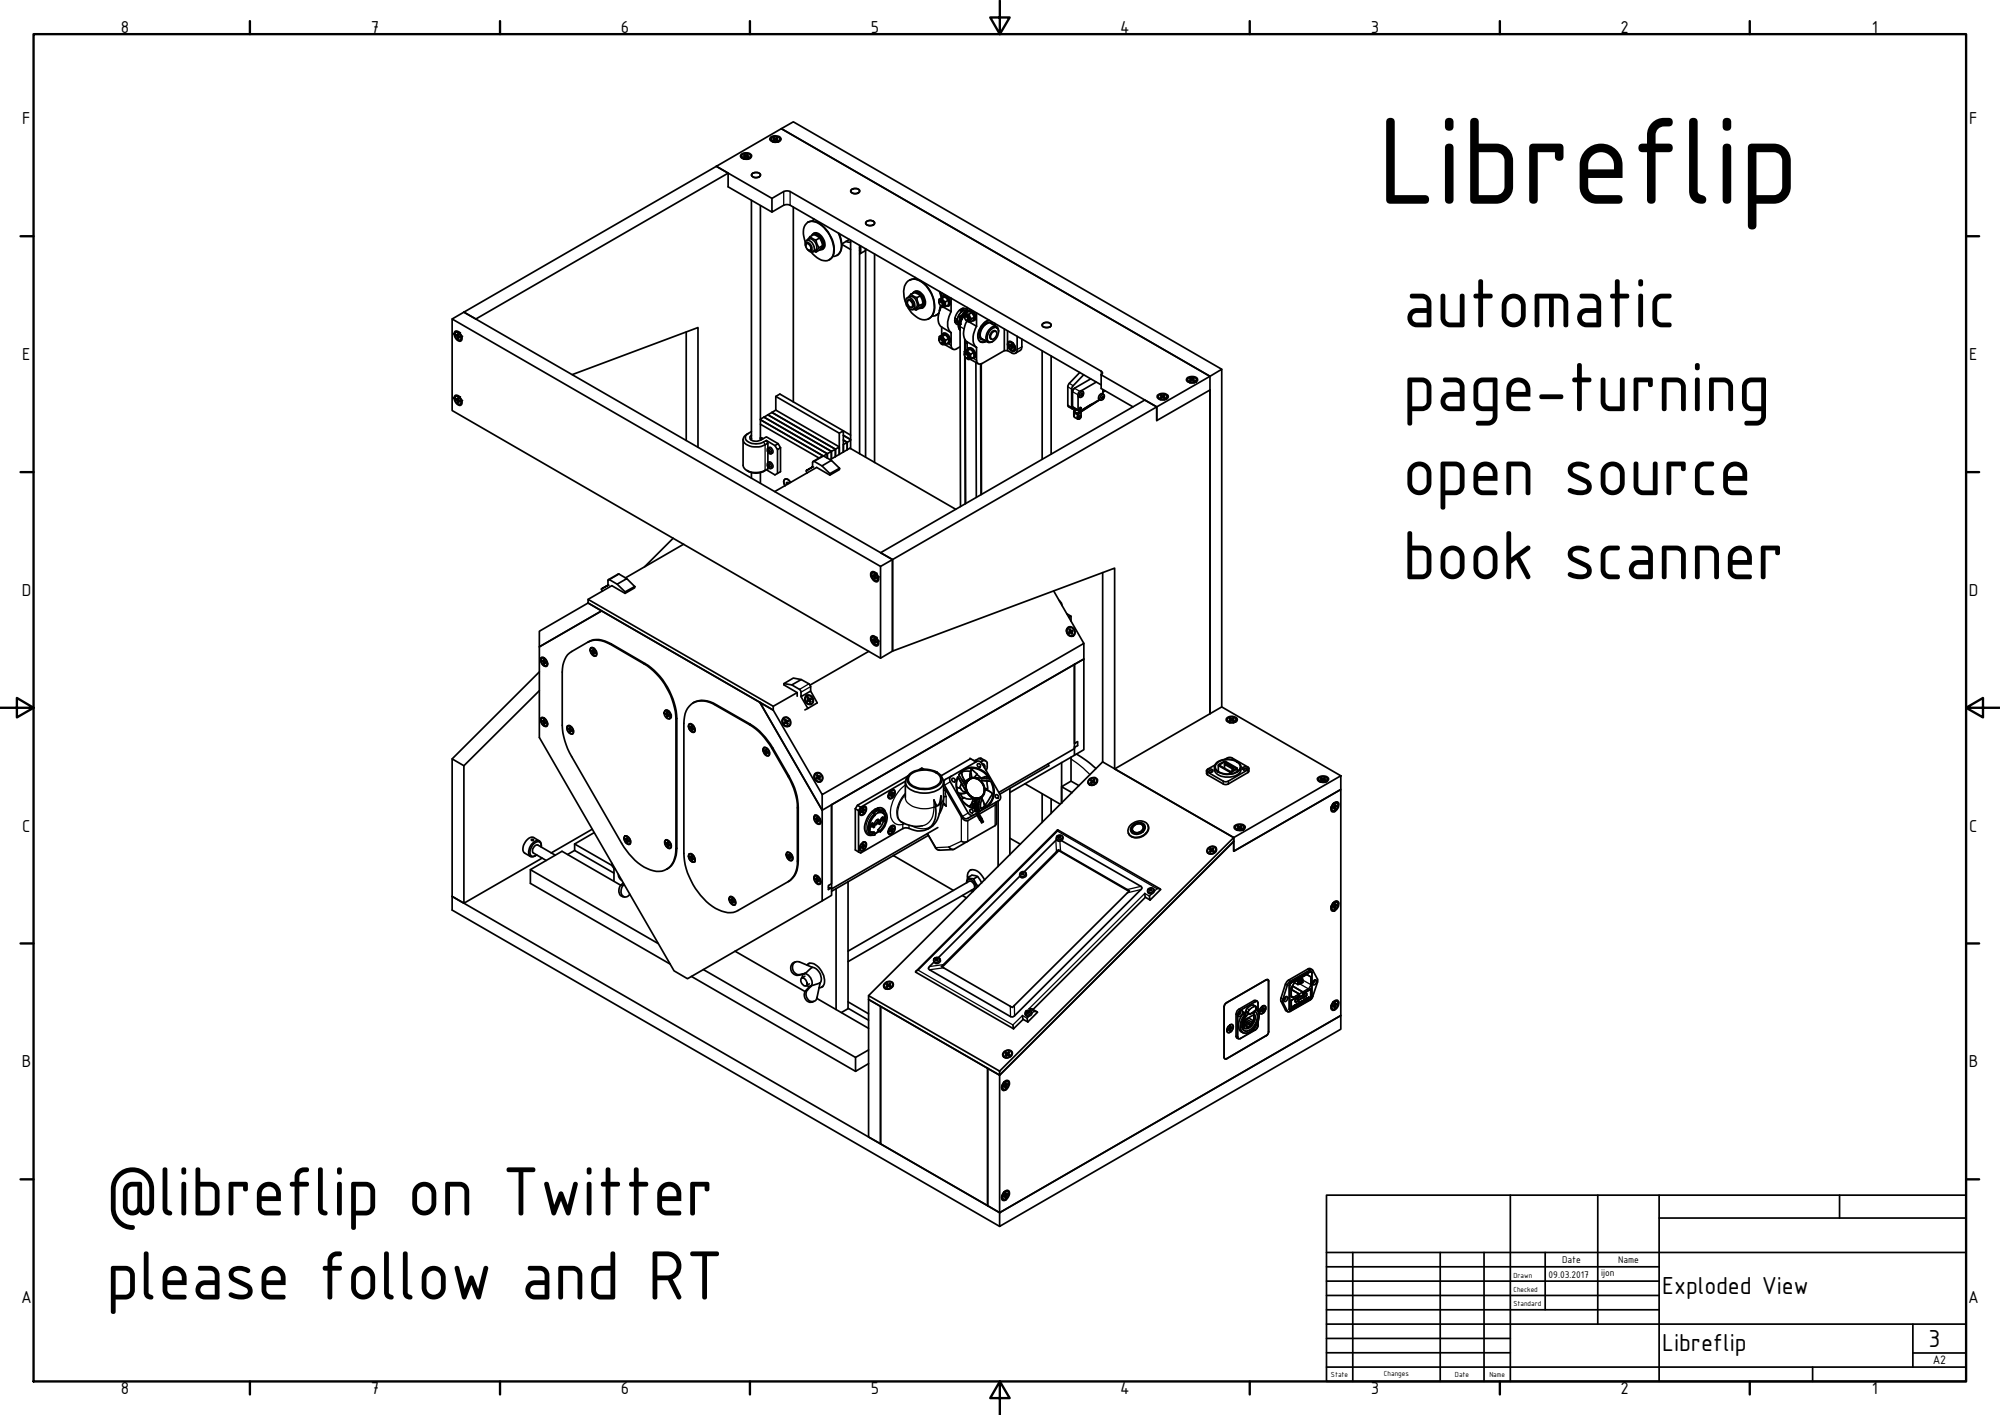
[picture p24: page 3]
Exploded View; Drawn; Checked; Date; Name; ijon; page-turning open source book scanner

@libreflip on Twitter
please follow and RT

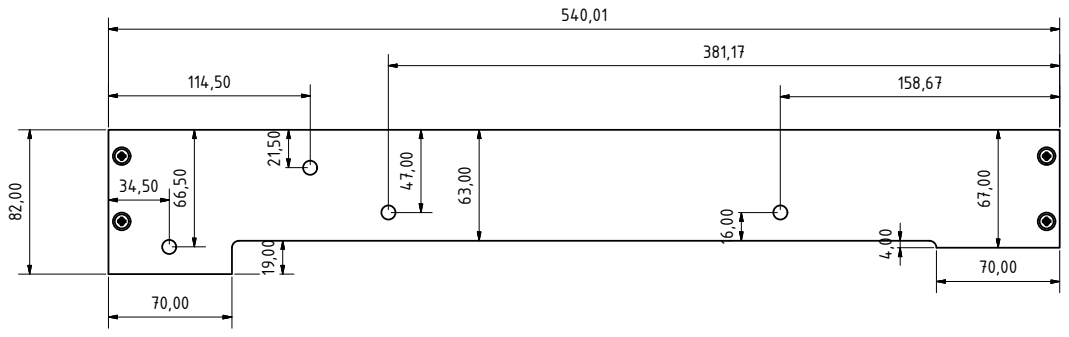
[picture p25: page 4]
Exploded View; Date; Name

Drawn | 09.03.2017 | ijon

Checked

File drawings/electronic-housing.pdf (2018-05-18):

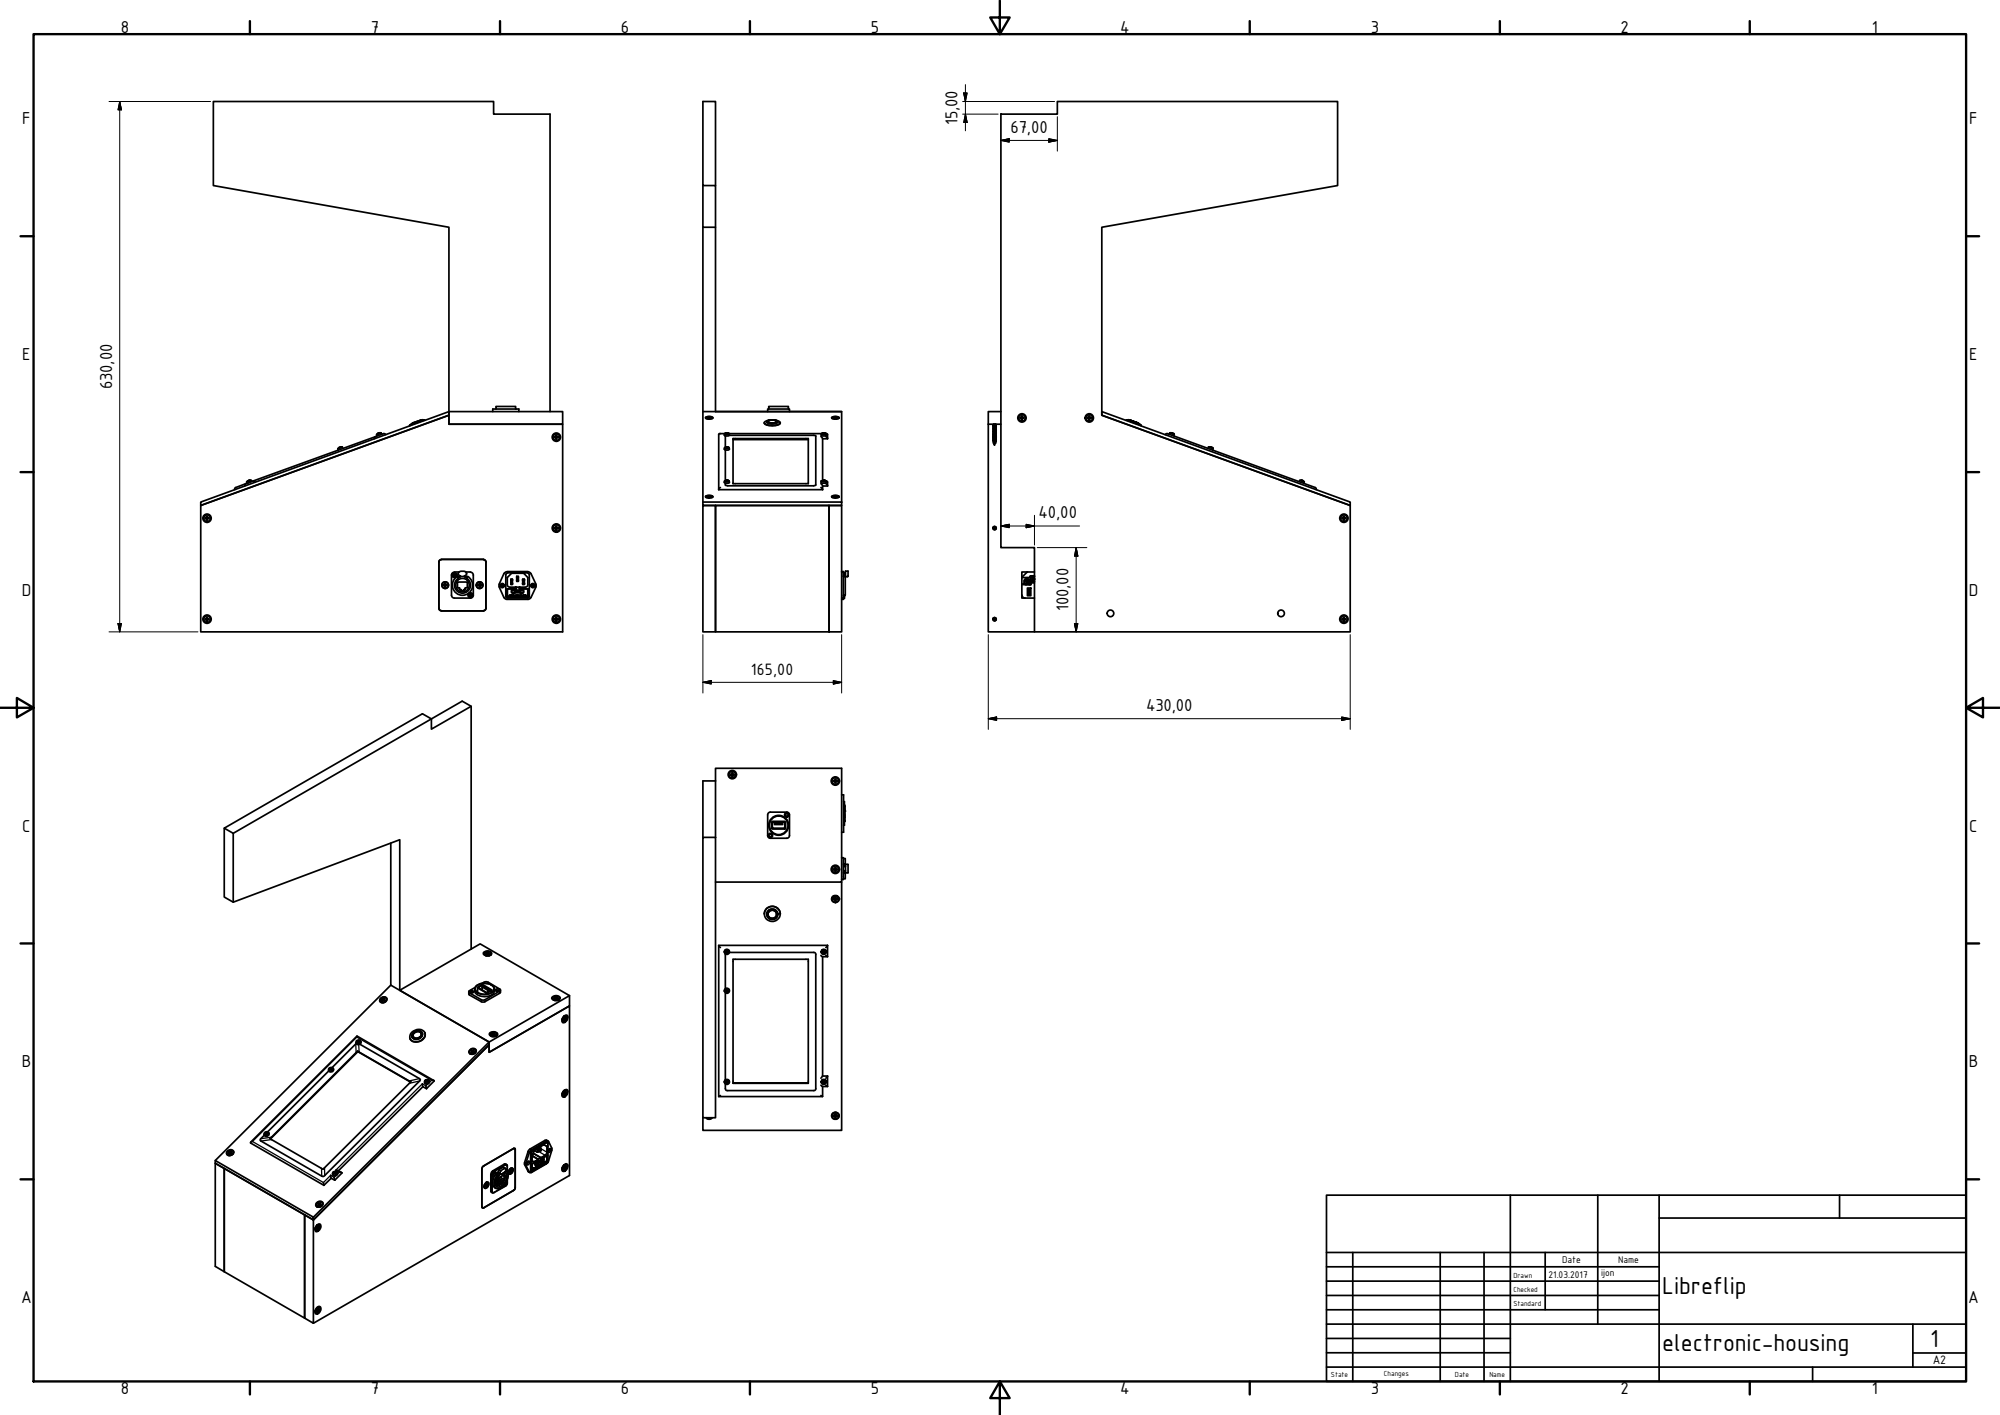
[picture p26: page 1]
Libreflip; electronic-housing; State; Changes; Date; Name; Drawn; Checked; Standard; ijon

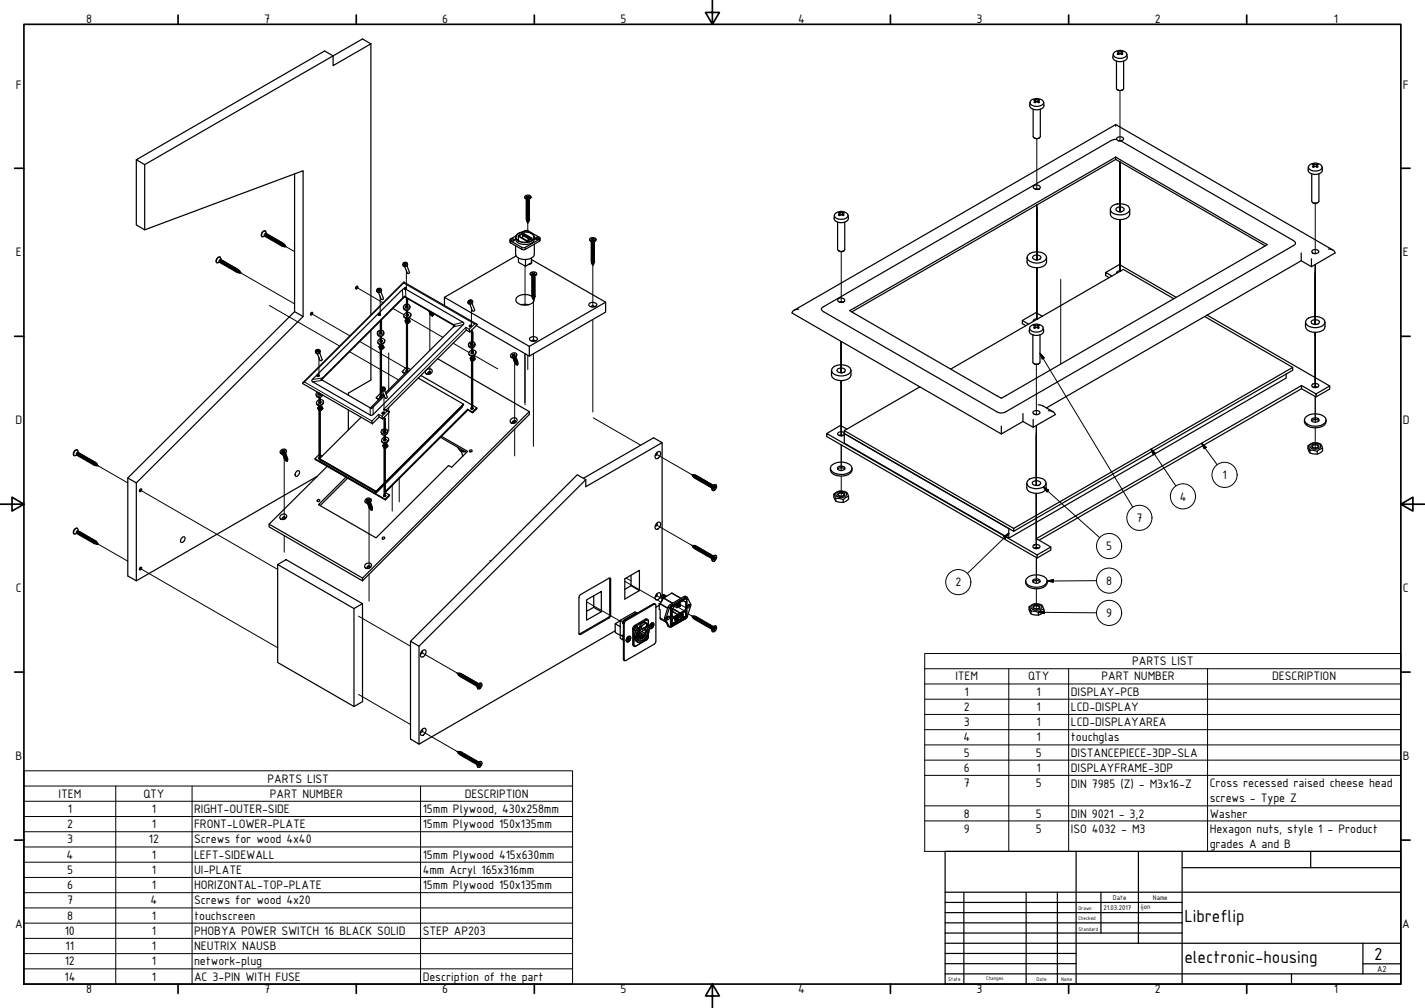
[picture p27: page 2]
PARTS LIST; ITEM; QTY; PART NUMBER; DESCRIPTION; RIGHT-OUTER-SIDE; 15mm Plywood, 430x258mm; FRONT-LOWER-PLATE; 15mm Plywood 150x135mm; Screws for wood 4x40; LEFT-SIDEWALL; 15mm Plywood 415x630mm; UI-PLATE; 4mm Acryl 165x316mm; HORIZONTAL-TOP-PLATE; Screws for wood 4x20; touchscreen; PHOBYA POWER SWITCH 16 BLACK SOLID; STEP AP203; NEUTRIX NAUSB; network-plug; AC 3-PIN WITH FUSE; Description of the part; DISPLAY-PCB; LCD-DISPLAY; LCD-DISPLAYAREA; touchglas; DISTANCEPIECE-3DP-SLA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

Cross recessed raised cheese head
screws - Type Z

Hexagon nuts, style 1 - Product
grades A and B

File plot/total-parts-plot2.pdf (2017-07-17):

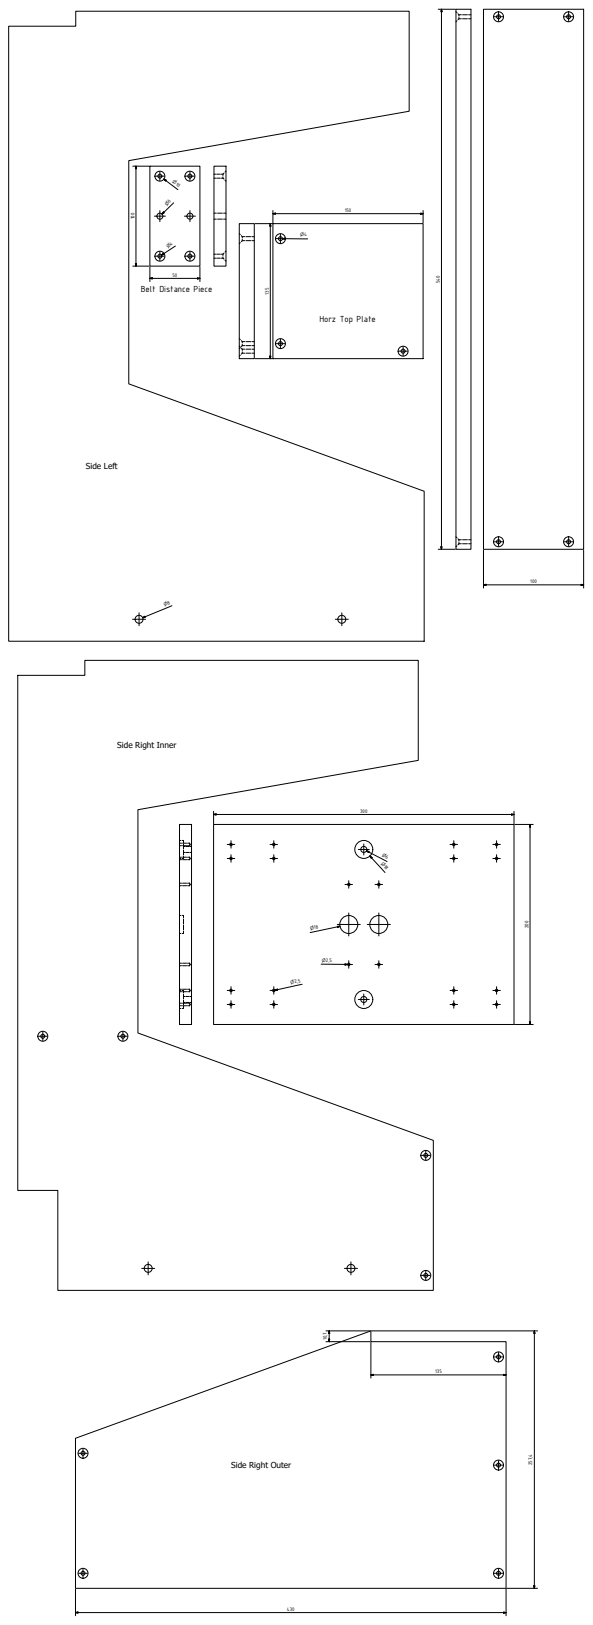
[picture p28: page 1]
Side Left

Belt Distance Piece

Horz Top Plate

Side Right Inner

Side Right Outer

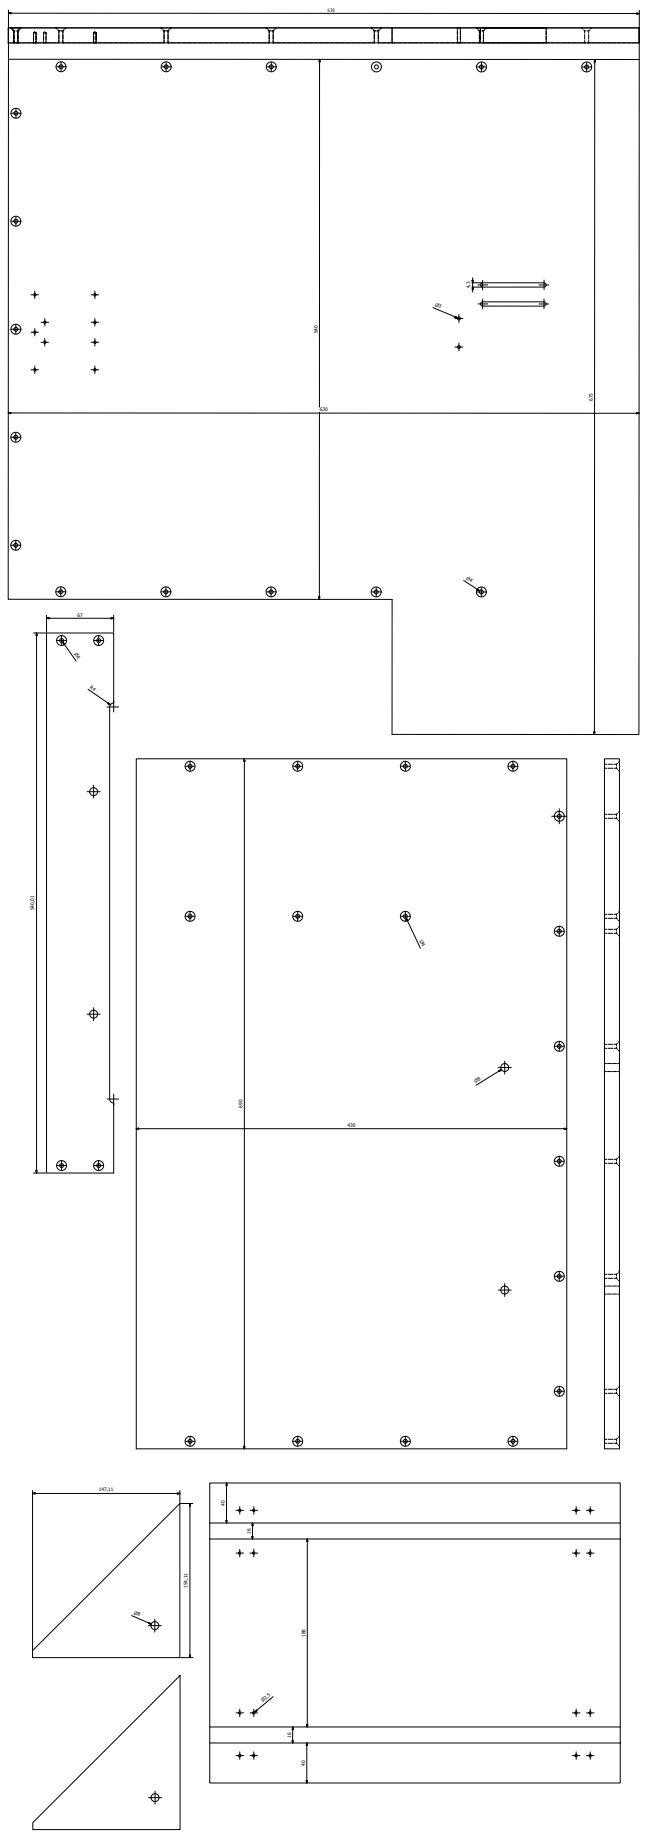
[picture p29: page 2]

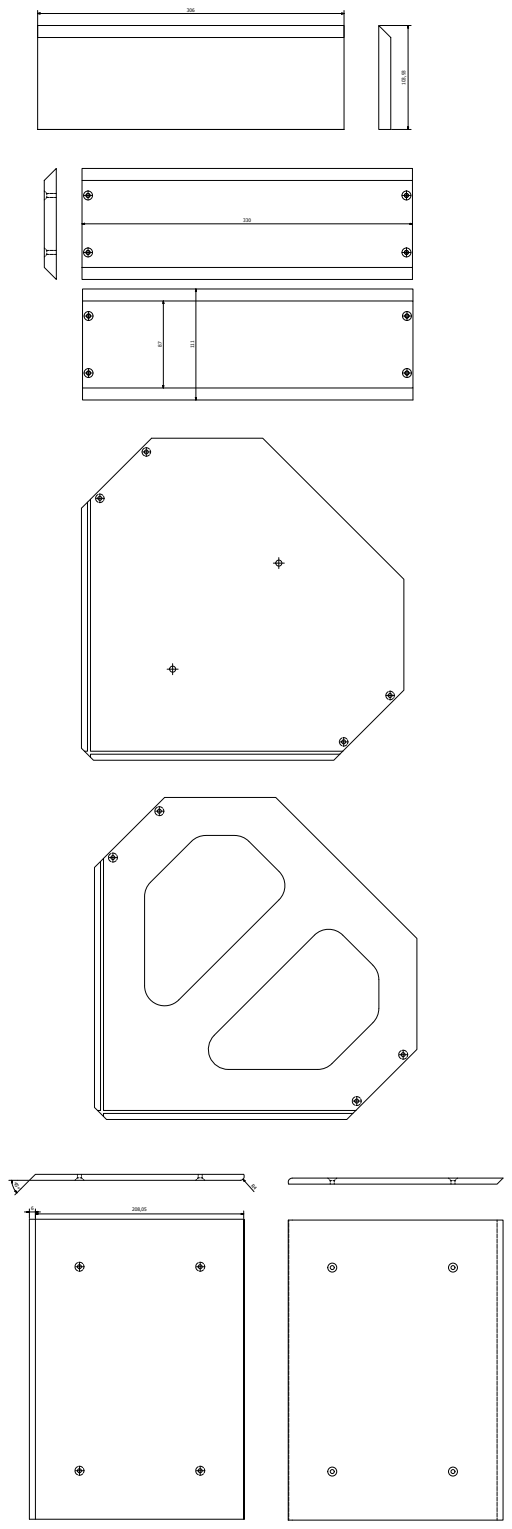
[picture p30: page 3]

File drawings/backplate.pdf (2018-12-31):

A ( 1 : 2 )

B ( 1 : 2 )

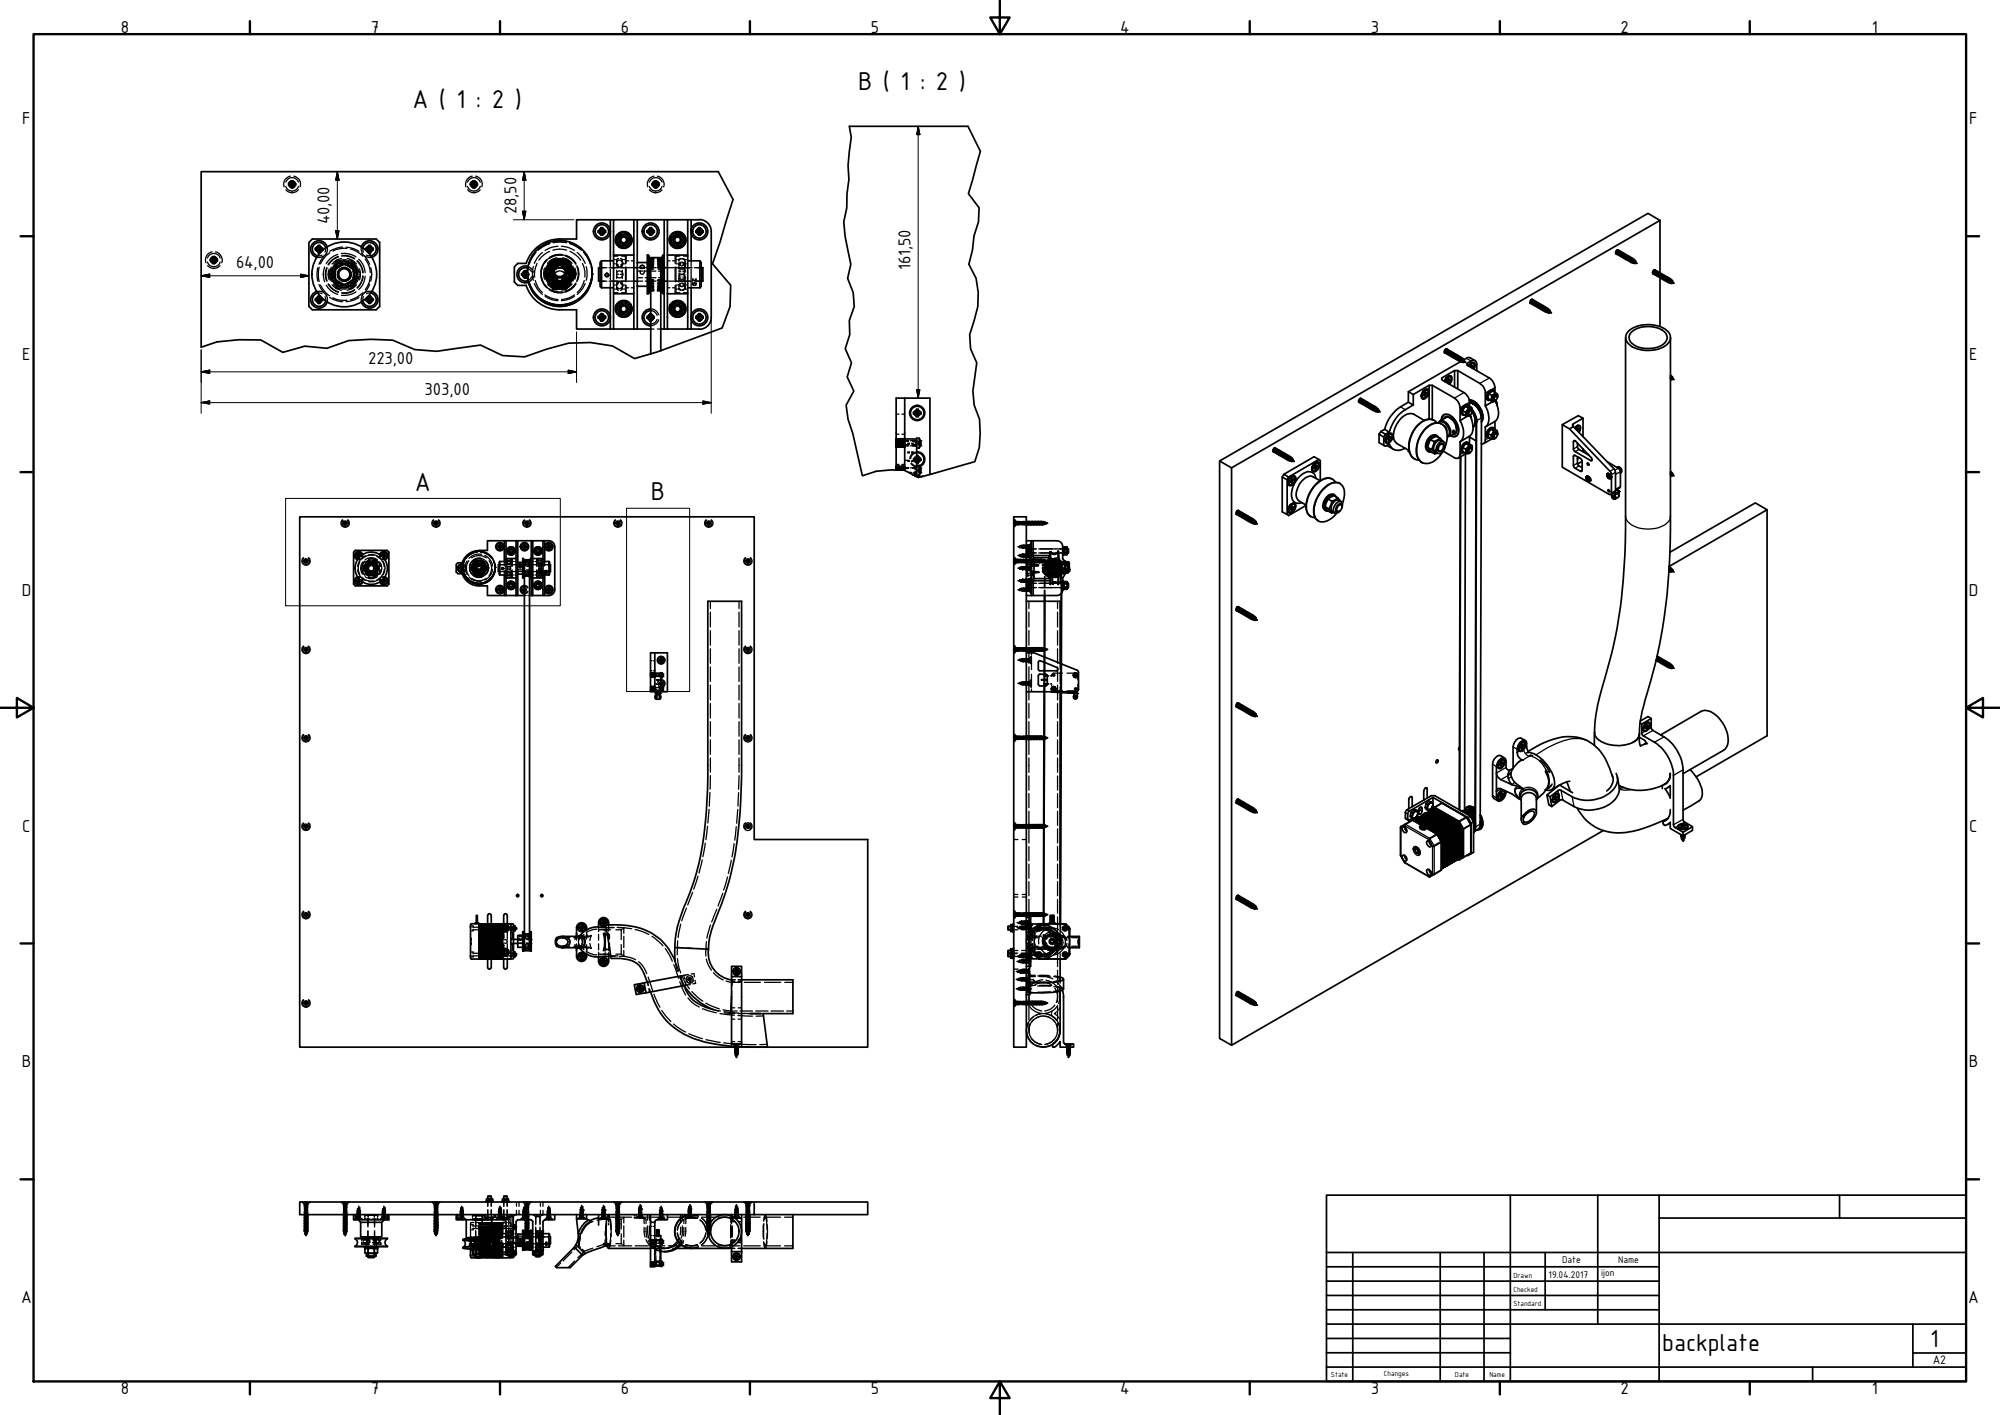
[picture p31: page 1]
backplate; State; Changes; Date; Name; Drawn; Checked; Standard; ijon

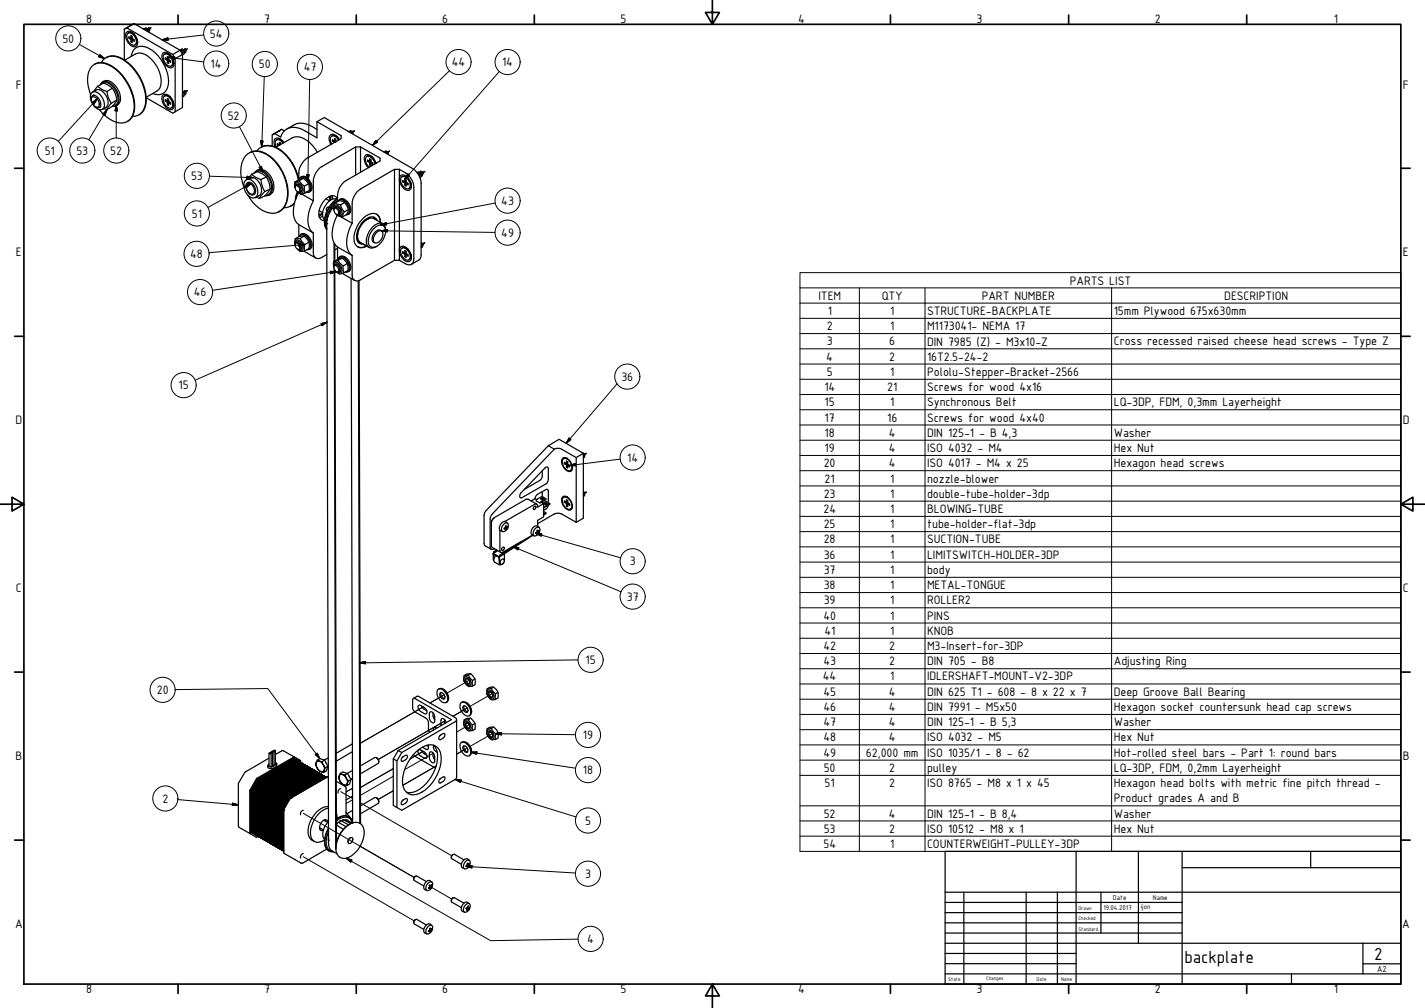
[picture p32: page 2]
LIS; T ITEM; QTY; PART NUMBER; RIP; TIO; DIN; ais; eig; WIN; LIMIT; WIT; PIN; tin; Rin; rin; wit; ric; fin; pit; EIG

LIS; T ITEM; QTY; PART NUMBER; RIP; TIO; eig; RIN; Lin; rin; ais; DIN; 1: round bars; tin; Rin

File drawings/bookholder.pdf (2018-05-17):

PARTS LIST; ITEM; QTY; PART NUMBER; DESCRIPTION; 15mm Plywood 410x300mm; BOOKHOLDER-BASE; linear-bearing-holder; V-SHAPE-CRADDLE; BOOKHOLDER-FASTENER; bookholder2; State; Changes; Date; Name; Drawn; Checked; Standard; ijon

PARTS LIST; ITEM; QTY; PART NUMBER; DESCRIPTION; DIN 976-1 - M8 x 1000 - A; ISO 4032 - M8; Hex Nut; DIN 315 - M8; Wing Nut; DIN 9021 - 8,4; Washer; LQ-3DP, FDM, 0,3mm Layerheight; LINEAR-BEARING-HOLDER-3DP; LM8UU 8mm Linear Bearing; Screws for wood 4x20; 15mm Plywood 155x148mm; BOOKHOLDER-PLATE; 6mm Plywood 215x300mm; bookholder2; State; Changes; Date; Name; Drawn; Checked; Standard; ijon

Stud bolts - Part 1:
Metric thread

VERTICAL-PART-BOOKH
OLDER



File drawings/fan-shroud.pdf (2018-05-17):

PARTS LIST; ITEM; QTY; PART NUMBER; DESCRIPTION; DUMMYSHAPE-FLUTTERFAN; 40X40X10 DC FAN; SHROUD-V2-3DP; Screws for wood 4x12; fan-shroud2; State; Changes; Date; Name; Drawn; Checked; Standard; ijon.me

Pageflutter-Fan with Shroud

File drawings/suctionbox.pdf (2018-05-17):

PARTS LIST; ITEM; QTY; PART NUMBER; DESCRIPTION; antiglare-glas; 3mm AntiglareGlas 314x243mm; glas-separator; HQ-3DP with SLA; SUCTIONBOX-FRONT; 12mm Plywood 357x348mm; SIDE-SUCTIONBOX; 12mm Plywood 104x306mm; SUCTIONBOX-CAMERABOARD; 12mm Plywood 111x330mm; SUCTIONBOX-TOP-GLAS; 4mm AntiglareGlas 234x330mm; Screws for wood 4x40; top-glas-hold-down; see3cam; fan-shroud; baro-sensor; SUCTIONBOX-FRONT-WINDOW; HOSE-ADAPTER-SUCTIONBOX; Screws for wood 4x12; suctionbox; State; Changes; Date; Name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

Date; Name

Drawn | 13.03.2017 | ijon

Checked

Drawn; Checked; Date; Name; ijon

tio

PARTS LIST; ITEM QTY; PART NUMBER; DESCRIPTION; SEE3CAM_CU130_MOD_3D_DRAWING; SEE3CAM_CU130_BASE_3D_DRAWING; CAMERA-HOLDER-MOVABLE; ISO 4762 - M3 x 25; Hexagon Socket Head Cap Screw; DIN 9021 - 3,2; Washer; 4 DIN 555-5 - M3; Hex Nut; ISO 4032 - M3; CAMERA-HOLDER-FIXED; Screws for wood 4x12; M3-Insert-for-3DP; CAMERA-HOLDDOWN; 4 DIN 7985 (Z) - M3x10-Z; Cross recessed raised cheese head screws - Type Z; Drawn; Checked; Date; Name; ijon

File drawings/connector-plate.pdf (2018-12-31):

LIS; T ITEM; QTY; PART NUMBER; RIP; TIO; VIN; LIN; RIN; eig; Lin; rin; DIS; PIE; DIN; FIN

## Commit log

2017-07-17 prototype version1 complete
    [1pcs-belt-lock.stl, 1pcs-displayframe-3dp.stl, 1pcs-idlershaft-mount.stl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]
2018-05-13 updated some cad-files
    [1pcs-double-tube-holder-3dp.stl, 1pcs-hose-adapter-bulkhead-lower-3dp.stl, 1pcs-hose-adapter-bulkhead-upper-3dp.stl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]
2018-05-17 exported all cad-drawings with current state as pdf
    [suctionbox.idw]
2018-05-18 added powerplug and network socket
2018-05-19 new 3d-printed parts added
    [1pcs-baro-sens-cable-HOLDclamp-3dp.stl, 1pcs-baro-sensor-holder-3dp.stl, 1pcs-m4-wrench.ipt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]
2018-09-30 Redesign of many parts and some new as well
    [1pcs-counterweight-pulley-3dp.stl, 1pcs-idlershaft-mount-v2.stl, 2pcs-CW-bearing-holder-orient1-3dp.stl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]
2018-09-30 old version, needs deletion because of new counterweight
    [1pcs-idlershaft-mount.stl]
2018-12-31 general update of several changes
    [1pcs-idlershaft-mount-v3.stl, 1pcs-idlershaft-mount.stl, 1pcs-m4-wrench.ipt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]
2026-07-22 Add new light holder part (no suction cup, screw-mounted)
    Replaces the previous light holder — this version is screwed in
    instead of relying on suction cups.
    [2pcs-lightholder-new.stl]
2026-07-22 Remove old light-rod-holder-lower part
    Replaced by 2pcs-lightholder-new.stl (screw-mounted, no suction cup).
    [2pcs-light-rod-holder-lower-3dp.stl]
